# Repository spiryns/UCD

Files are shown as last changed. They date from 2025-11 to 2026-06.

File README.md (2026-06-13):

# SensePath
### Ear-free, intuitive navigation indoors

🛠️ Built by **Sam Piryns**, **Titus Impens**, **Han Deburchgraeve**  
🔥 Supervised by `prof. dr. Bas Baccarne`, `Yannick Christiaens` & `Wouter Devriese`  
🌱 Grown at `Ghent University` 🏛️ `Industrial Design Engineering` ([project overview](https://github.com/basbaccarne/human-centered-design))

*Juni 2026*

---

## Introductie

Mensen die blind of slechtziend zijn navigeren buitenshuis relatief goed met GPS, maar in grote publieke gebouwen (stations, ziekenhuizen, campussen) valt die ondersteuning weg. Vooral op kruispunten, splitsingen en bij tijdelijke omleidingen leidt dit tot twijfel, extra mentale belasting en afhankelijkheid van hulp van anderen.

We onderzochten dit via deskresearch en benchmarking van bestaande (indoor) navigatieoplossingen, en via user interviews en feedbackmomenten met gebruikers en organisaties uit de blinden- en mobiliteitswereld. Daaruit kwamen duidelijke noden naar voren: betrouwbare "decision support" op keuzemomenten, zo weinig mogelijk telefoongebruik tijdens het stappen, en discrete feedback die ook in publieke context bruikbaar is.

Onze oplossing is **SensePath**: een **tweedelige witte stok** die wij volledig als systeem leveren. Het onderstuk volgt de conventionele opbouw van bestaande witte stokken (gewicht, lengte, verwisselbare pin-tip), maar heeft bovenaan een **3D-geprinte schroefdraad** op het uiteinde. Daarop wordt ofwel een **tech-handvat** geschroefd dat de elektronica voor haptische navigatiebegeleiding bevat, ofwel een **gewone handgreep** voor wanneer de route gekend is. Op die manier behoudt de gebruiker volledig zijn bestaande stok-ervaring en voegt SensePath alleen toe wat nodig is op onbekende trajecten. Het tech-handvat is gekoppeld aan een eenvoudige app-workflow en vertaalt route-informatie naar haptische begeleiding op het juiste moment (bv. bij keuzes en bochten), zodat de gebruiker "hands-free, heads-up" kan blijven bewegen met de stok als primair hulpmiddel. Zo maakt SensePath indoor navigatie zelfstandiger, rustiger en betrouwbaarder.

<p align="center">
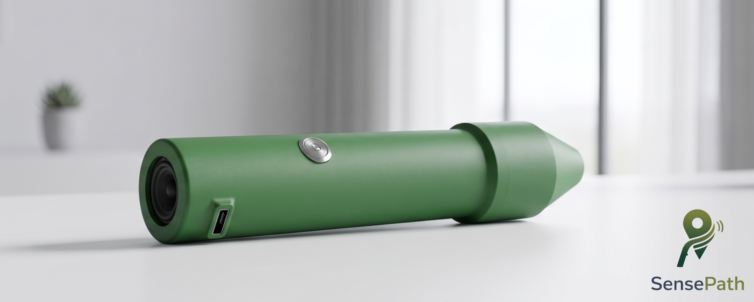
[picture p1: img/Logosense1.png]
SensePath logo
  
</p>

---

## Inhoudstafel

**Op deze pagina**

1. [Introductie](#introductie)
2. [Methodologie](#methodologie)
3. [Conclusie](#conclusie)
4. [Kritische reflectie](#kritische-reflectie)
5. [Noot inzake het gebruik van AI](#noot-inzake-het-gebruik-van-ai)
6. [Bijlagen](#bijlagen)
7. [Bronnen](#bronnen)
8. [Licentie](#licentie)

**Verdieping per fase** (Double Diamond)

1. [Discovery](docs/discovery.md)
2. [Definition](docs/definition.md)
3. [Design Requirements](docs/design_requirements.md)
4. [Develop 1](docs/develop_1.md) 
5. [Develop 2](docs/develop_2.md) 
6. [Develop 3](docs/develop_3_overzicht.md) 
7. [Deliver](docs/deliver.md) 

---

## Methodologie

Dit project volgt de **Double Diamond** aanpak (Discover, Define, Develop, Deliver), met nadruk op gebruikersgericht ontwerpen en iteratieve validatie. De tijdslijn hieronder toont de fasen, test-waves met sample-grootte (N) en de drie kritische pivots die het ontwerp stuurden.

```mermaid
timeline
    title SensePath → Double Diamond met test-waves en pivots
    section Discovery
        Okt 2025  : User interviews (N=3)
                  : Benchmarking 11 systemen
    section Definition
        Nov 2025  : Wave 1 conceptvalidatie (N=5)
        Dec 2025  : Wave 2 verfijning + MoSCoW (N=5)
                  : Pivot → volledige stok wordt afneembaar handvat
    section Develop
        Mrt 2026  : Develop 1 functionele tests (N=5)
        Apr 2026  : Develop 2 usability + ergonomie (N=5)
                  : Pivot → 3 trilmotoren wordt 1 LRA + DRV2605L
        Mei 2026  : Develop 3 microinteracties + CMF (N=5)
                  : Pivot → 10 trilpatronen wordt 3 kernsignalen (M4 M6 M9)
    section Deliver
        Jun 2026  : Validatieplan GPS-precisie en autonome wandeling
                  : Open vraag → Wizard-of-Oz wordt autonoom systeem
```

### Discovery (problem space)

In de discoveryfase werd de probleemruimte verkend via:

- **User interviews**: fricties, routines, copingstrategieën en contextfactoren identificeren (drukte, tijdelijke werken, knooppunten).
- **Deskresearch en benchmarking**: bestaande navigatie- en mobiliteitsoplossingen in kaart brengen en analyseren op feedbackmodaliteit, infrastructuurbehoefte, betrouwbaarheid en schaalbaarheid.

De resultaten werden samengebracht tot een probleemdefinitie, een eerste set **design requirements** en een initiële **PRD**. → 📄 [Volledige Discovery](docs/discovery.md)

### Definition (solution space)

In de definitionfase werd het concept getoetst en aangescherpt via **iteratief prototypen en testen** in twee waves:

- **Wave 1**: Vroege conceptvalidatie met low- tot mid-fidelity prototypes en Wizard-of-Oz scenario's. Focus op begrijpelijkheid, wenselijkheid en aanvaardbaarheid van de conceptrichting.
- **Wave 2**: Verfijning van interactie en feedback met nadruk op minimale smartphone-interactie, haptische feedback als primaire modaliteit, en een fail-safe workflow. Inclusief MoSCoW-prioritering en obstakeldetectie-observatietest.

→ 📄 [Volledige Definition](docs/definition.md)

### Develop (semester 2)

Technische uitwerking, interaction design, prototyping met oplopende fideliteit en usability testing in iteraties, verspreid over drie develop-iteraties. → 📄 [Develop 1](docs/develop_1.md) · [Develop 2](docs/develop_2.md) · [Develop 3](docs/develop_3_overzicht.md)

### Deliver (semester 2)

Finale validatie in realistische omgevingen, afronding prototype en documentatie. → 📄 [Volledige Deliver](docs/deliver.md)

📄 [Volledige methodologie](docs/methodologie.md)

---

## Conclusie

SensePath is een **tweedelige witte stok**: een conventioneel onderstuk met verwisselbare pin-tip en een **tech-handvat dat erop schroeft** via een 3D-geprinte schroefdraad. Dezelfde schroefverbinding accepteert ook een gewone handgreep, zodat de gebruiker dagelijks kan kiezen tussen tech-grip (onbekende routes) en standaard-grip (gekende routes) zonder dat hij van stok hoeft te wisselen. Het tech-handvat vertaalt routebeslissingen naar discrete haptische signalen in de hand. Drie kerncomponenten dragen het concept: één trilmotor die drie onderscheidbare microinteracties (obstakel, koersafwijking, bocht-aankondiging) levert, een sferisch kompaselement in de laagste gleufpositie dat continue richting voelbaar maakt via een servo-aandrijving, en de modulaire schroefverbinding die het hele systeem omkeerbaar maakt.

Waarom dit het juiste antwoord is op het probleem uit Discovery, is geen kwestie van technologie maar van **positionering**. SensePath vervangt het stok-gebruik niet ; we behouden de conventionele stok-opbouw en voegen alleen toe wat nodig is. Het onderstuk blijft de primaire obstakeldetector, het tech-handvat levert wat de stok zelf niet kan: oriëntatie op keuzemomenten zonder dat het gehoor of de smartphone-aandacht ingezet moet worden in het default-gebruik. Een opt-in spraak-fallback (default uit) bestaat als noodvariant. Daarmee adresseert het ontwerp de drie pijnpunten die de Discovery-interviews scherp maakten: onzekerheid aan knooppunten, de wens om het gehoor vrij te houden in publieke context, en de minimale-telefoon-eis tijdens het stappen.

De keuzes die deze positionering dragen, zijn telkens empirisch onderbouwd: de evolutie van 3 motoren naar 1 trilmotor (Develop 2), de versmalde gleuf zodat het kompas in de handpalm blijft (Develop 2), de reductie van 10 naar 3 trilpatronen (Develop 3), de keuze voor TPE Shore 65A overmold (Develop 3 CMF-deepdive). Voor de eindvalidatie wordt het kompas via een mini-servo aangestuurd, die de doelrichting **draadloos** ontvangt van een **aparte controller-module** die de testleider bedient ; daarmee kan het geheel realistisch getest worden zonder dat eerst een autonoom GPS-systeem geïntegreerd moet zijn. Volledige onderbouwing in [docs/design_requirements.md](docs/design_requirements.md).

Het MVP-prototype bestaat uit **drie onderdelen**: het stok-onderstuk, het tech-handvat dat erop schroeft, en de **besturing** — de fysieke Wizard-of-Oz controller-module (eigen XIAO ESP32-C3, batterij en KY-040 encoder, draadloos via ESP-NOW) samen met de digitale software (firmware op handvat en controller + telefoon-app). Het rapport onderscheidt bewust **het beoogde eindproduct** (productie-vorm met hoog-nauwkeurige RTK GNSS via FLEPOS / WALCORS, smartphone-app, ToF-obstakeldetectie en productie-materialen) van **ons MVP-prototype** (academisch deliverable met PLA-print, aparte controller-module als Wizard-of-Oz vervanger voor GPS, en bewust geen obstakeldetectie). Beide niveaus en de vertaalstap ertussen worden uiteengezet in de [Deliver](docs/deliver.md)-sectie. Voor de open onderzoeksvragen en aanbevelingen voor vervolgwerk: zie [Kritische reflectie](#kritische-reflectie).

<p align="center">
  Render van SensePath in gebruik bij indoor navigatie
  <br/><em>SensePath in gebruik: indoor navigatie met de tweedelige witte stok.</em>
</p>

---

## Kritische reflectie

Dit project levert een prototype af dat zijn kerninteractie heeft gevalideerd, maar laat tegelijk vijf open vragen achter die mee bepalen hoe SensePath zich vanaf hier verder kan ontwikkelen. Per-fase reflecties staan binnen [Develop 1](docs/develop_1.md#kritische-reflectie-develop-1), [Develop 2](docs/develop_2.md#kritische-reflectie-develop-2) en [Develop 3](docs/develop_3_overzicht.md#kritische-reflectie-develop-3) ; deze synthese trekt ze samen tot aanbevelingen voor vervolgwerk.

**Sample-grootte en doelgroep-heterogeniteit**. De cumulatieve N over alle Develop-fasen blijft beperkt (Develop 1 N=5, Develop 2 N=5, Develop 3 N=3 blinde + N=2 geblinddoekte ziende controles). De convergentie tussen Mario en Herman op richtinginformatie-in-patroon is sterk, maar Jelle's tegengestelde voorkeur toont dat de doelgroep heterogeen is. Aanbeveling: een vervolgstudie met N=15 → 20 over verschillende leeftijdscategorieën en tech-affiniteitsniveaus om de instelbaarheids-vraag te kwantificeren.

**De Wizard-of-Oz ↔ autonoom systeem vertaling**. 90% van de gemeten fouten in Develop 1 was herleidbaar tot wizard-timing, niet tot gebruikersgedrag of feedbackkwaliteit. Onze test-instrumentatie zit daarmee tussen het ontwerp en de waarheid. Aanbeveling: de finale validatie moet plaatsvinden met een autonoom systeem (GPS- of opgenomen-route-gestuurd) zodat het foutpercentage de feedbackkwaliteit reflecteert in plaats van de wizard-snelheid.

**CMF-deepdive analytisch, niet empirisch**. De keuzes voor TPE Shore 65A overmold, fijne radiale ribbels, POM-knoppen en aluminium pin scoren hoog op weegtabellen onderbouwd met literatuur, maar werden niet als gecombineerd prototype getest met eindgebruikers. Aanbeveling: één-op-één fysieke variant 3D-printen in finale materialen en blind laten beoordelen door dezelfde testers, om de CMF-keuzes empirisch te bevestigen.

**Indoor-focus vs outdoor-robuustheid**. De huidige use case is indoor wayfinding, maar GPS-precisie is buiten de scope van Develop 3 niet getoetst en regen/handschoenen evenmin. Herman's winter-zorg ("ik vrees dat ons pinnetje in de winter niet voelbaar zal zijn") en zijn vraag over uur-plus wandelingen zijn onbewezen aannames. Aanbeveling: outdoor field-test in wisselende weersomstandigheden met sessies van minstens 45 minuten, plus een vervangbare pin-tip uit verschillende materialen (TPE-soft, TPE-hard, rubber).

**Stations als gerichte use-case**. Alle drie de blinde testers wezen spontaan op stations als doel-context. Dit suggereert dat een gerichte go-to-market (stations + ziekenhuizen + campussen) sterker is dan een algemene indoor-positionering. Deze pivot ligt buiten de academische scope van dit project maar verdient verkenning bij een eventuele product-vervolg-traject (VLAIO, RIZIV-terugbetaling, samenwerking NMBS-toegankelijkheid).

Deze vijf punten zijn niet beperkingen van het ontwerp, maar van de manier waarop we het tot nu hebben kunnen valideren. Ze definiëren mee de onderzoeksagenda voor wie dit project zou verderzetten.

---

## Noot inzake het gebruik van AI

Binnen dit project werden meerdere AI-tools ingezet als ondersteunend hulpmiddel:

- **Tekst en rapportage**: Claude (Anthropic) werd gebruikt om ruwe notities en onderzoeksdata te structureren tot leesbare paragrafen en om teksten taalkundig te verfijnen. De inhoudelijke keuzes, analyses en conclusies zijn steeds door het team zelf gemaakt.
- **Benchmarking en analyse**: AI werd ingezet om publiek beschikbare informatie samen te vatten, vergelijkingscriteria te structureren en eerste analyses te genereren. Alle bevindingen werden handmatig geverifieerd.
- **Storyboard**: Het script werd geschreven met Claude Code, image direction via ChatGPT (GPT-4o), en de uiteindelijke beeldgeneratie via NanoBanana (Gemini 3 Pro Image).
- **Codering**: Claude en Gemini werden gebruikt voor ondersteuning bij de ESP32-firmware en de Wizard-of-Oz controller-app.

AI werd **niet** ingezet voor het uitvoeren of analyseren van user interviews, het nemen van ontwerpbeslissingen, of het formuleren van design requirements. Deze zijn volledig gebaseerd op eigen gebruikersonderzoek en teamreflectie.

> *"All content in this document has been reviewed and approved by the author. AI tools were used solely to support text processing, coding, and image editing, not for generating research data or conclusions."*

---

## Bijlagen

### Verdieping per fase

| Fase | Pagina |
|---|---|
| Discovery | [docs/discovery.md](docs/discovery.md) |
| Definition | [docs/definition.md](docs/definition.md) |
| Design Requirements | [docs/design_requirements.md](docs/design_requirements.md) |
| Develop 1 | [docs/develop_1.md](docs/develop_1.md) |
| Develop 2 | [docs/develop_2.md](docs/develop_2.md) |
| Develop 3 (overzicht) | [docs/develop_3_overzicht.md](docs/develop_3_overzicht.md) |
| Develop 3 (UX & Service Design) | [docs/develop_3.md](docs/develop_3.md) |
| Deliver | [docs/deliver.md](docs/deliver.md) |
| Methodologie | [docs/methodologie.md](docs/methodologie.md) |

### Discovery

| Document | Link |
|---|---|
| Interview protocol | [Interview - protocol - SensePath.docx](reports%20and%20protocols/Interview%20-%20protocol%20-%20SensePath.docx) |
| Onderzoeksrapport interviews | [Onderzoeksrapport_user_interviews_SensePath.docx](reports%20and%20protocols/Onderzoeksrapport_user_interviews_SensePath.docx) |
| Benchmarking protocol | [Benchmarkingprotocol_SensePath.docx](reports%20and%20protocols/Benchmarkingprotocol_SensePath.docx) |
| Benchmarking rapport | [Benchmarkingrapport_SensePath.docx](reports%20and%20protocols/Benchmarkingrapport%20_SensePath.docx) |

### Definition

| Document | Link |
|---|---|
| Wave 1 → Protocol | [testprotocol_define_WAVE1.pdf](reports%20and%20protocols/testprotocol_define_WAVE1.pdf) |
| Wave 1 → Rapport | [Report_define_WAVE1.pdf](reports%20and%20protocols/Report_define_WAVE1.pdf) |
| Wave 2 → Protocol | [testprotocol_define_WAVE2.pdf](reports%20and%20protocols/testprotocol_define_WAVE2.pdf) |
| Wave 2 → Rapport | [Report wave 2.pdf](reports%20and%20protocols/Report%20wave%202.pdf) |

### Develop

| Document | Link |
|---|---|
| Develop 1 → Rapport | [Report_SensePath_Develop_1.pdf](reports%20and%20protocols/Report_SensePath_Devolop_1.pdf) |
| Develop 1 → Protocol | [protocol_sensepath_develop1.docx](reports%20and%20protocols/protocol_sensepath_develop1.docx) |
| Develop 2 → Protocol | [protocol_sensepath_develop2_PDF.pdf](reports%20and%20protocols/protocol_sensepath_develop2_PDF.pdf) |
| Develop 2 → Rapport | [Rapport_Dev2_PDF.pdf](reports%20and%20protocols/Rapport_Dev2_PDF.pdf) |
| Develop 3 → Protocol | [protocol_sensepath_develop3_PDF.pdf](reports%20and%20protocols/protocol_sensepath_develop3_PDF.pdf) |
| Develop 3 → Rapport | [rapport_sensepath_develop3.pdf](reports%20and%20protocols/rapport_sensepath_develop3.pdf) |
| Develop 3 → UX & Service Design uitwerking | [develop_3.md](docs/develop_3.md) |
| Develop 3 → Service Blueprint | [service_blueprint.png](docs/develop_3/img/service_blueprint.png) |
| Develop 3 → Customer Journey Map | [customer_journey.png](docs/develop_3/img/customer_journey.png) |
| Develop 3 → Stakeholder Map | [stakeholder_map.png](docs/develop_3/img/stakeholder_map.png) |
| Develop 3 → Norman's drie lagen | [norman_layers.png](docs/develop_3/norman_layers.png) |
| Develop 3 → Emotion Map | [emotion_map.png](docs/develop_3/emotion_map.png) |
| Develop 3 → Microinteractions overzicht | [microinteractions.png](docs/develop_3/microinteractions.png) |

### Deliver

| Document | Link |
|---|---|
| Bill of Materials | [docs/bom.md](docs/bom.md) |
| Schakelschema | [docs/wiring.md](docs/wiring.md) |
| Build guide | [docs/build_guide.md](docs/build_guide.md) |
| Software-architectuur | [docs/software.md](docs/software.md) |
| CAD-bestanden | [cad/](cad/) |
| Volledig 3D-model handvat (STEP) | [cad/Finaal Prototype.stp](cad/Finaal%20Prototype.stp) |
| CAD-exports (STL per onderdeel) | [cad/exports/](cad/exports/) |
| Firmware handvat | [src/firmware/handle/main.cpp](src/firmware/handle/main.cpp) |
| Firmware controller | [src/firmware/controller/main.cpp](src/firmware/controller/main.cpp) |
| Telefoon-app | [src/app/](src/app/) |

---

## Bronnen

### Wetenschappelijke literatuur

- Liu, G., Yu, T., Yu, C., Xu, H., Xu, S., Yang, C., Wang, F., Mi, H., & Shi, Y. (2021). Tactile Compass: Enabling visually impaired people to follow a path with continuous directional feedback. *Proceedings of the 2021 CHI Conference on Human Factors in Computing Systems*. ACM. https://doi.org/10.1145/3411764.3445644
- Guerreiro, J., Ahmetovic, D., Sato, D., Kitani, K., & Asakawa, C. (2019). Airport accessibility and navigation assistance for people with visual impairments. *Proceedings of the 2019 CHI Conference on Human Factors in Computing Systems*, 1-14.
- Slade, P., Tambe, A., & Kochenderfer, M. J. (2021). Multimodal sensing and intuitive steering assistance improve navigation and mobility for people with impaired vision. *Science Robotics, 6*(59), eabg6594.
- Martiniello, N., et al. (2020). *Aesthetics and perceived stigma of assistive technology for people with visual impairment.* (Geciteerd in de Develop 3 UX- en CMF-onderbouwing.)
- Alary, F., et al. (2008). *Tactile acuity in the blind: a psychophysical study using a two-dimensional angle discrimination task.* Experimental Brain Research. (Tactiele drempelwaarden bij blinde gebruikers.)
- Skedung, L., et al. (2018). *Tactiele perceptie van fijne oppervlaktetexturen.* (Leesbaarheid van grip-texturen voor oudere handen.)
- Shostack, G. L. (1984). Designing services that deliver. *Harvard Business Review, 62*(1), 133-139.
- Fogg, B. J. (2009). A behavior model for persuasive design. *Proceedings of the 4th International Conference on Persuasive Technology (Persuasive '09)*. ACM.
- Vaes, K. (2014). *Product Stigmaticity: Understanding, measuring and managing product-related stigma* [Doctoraatsproefschrift, TU Delft & Universiteit Antwerpen].
- Wertheimer, M. (1923). *Untersuchungen zur Lehre von der Gestalt* (Gestalt-perceptiewetten).

### Ontwerptheorie & boeken

- Norman, D. A. (2013). *The Design of Everyday Things: Revised and Expanded Edition.* Basic Books.
- Norman, D. A. (2004). *Emotional Design: Why We Love (or Hate) Everyday Things.* Basic Books.
- Norman, D. A. (2011). *Living with Complexity.* MIT Press.
- Saffer, D. (2013). *Microinteractions: Designing with Details.* O'Reilly Media.
- Eyal, N. (2014). *Hooked: How to Build Habit-Forming Products.* Portfolio / Penguin.
- Walter, A. (2011). *Designing for Emotion.* A Book Apart.

### Normen, standaarden & richtlijnen

- ISO 9999:2016. *Assistive products for persons with disability — Classification and terminology.* International Organization for Standardization.
- World Health Organization. (2016). *Priority assistive products list (APL)* en *Assistive product specifications (APS).* WHO.
- World Health Organization. (2023). *Blindness and vision impairment.* Geraadpleegd van https://www.who.int/news-room/fact-sheets/detail/blindness-and-visual-impairment
- Gordon, C. C., et al. (2014). *2012 Anthropometric Survey of U.S. Army Personnel: Methods and Summary Statistics (ANSUR II).* U.S. Army Natick Soldier RD&E Center.

### Methodologie

- Design Council. (2005). *The Double Diamond: A universally accepted depiction of the design process.* Geraadpleegd van https://www.designcouncil.org.uk/double-diamond

### Positionerings-infrastructuur

- Digitaal Vlaanderen. *FLEPOS — Flemish Positioning Service* (RTK GNSS-correcties via NTRIP).
- Service public de Wallonie (SPW). *WALCORS — Walloon Continuously Operating Reference Stations.*

### Cursusmateriaal (Gebruiksgericht Ontwerpen, Universiteit Gent)

- Baccarne, B. (2025-2026). *Project Gebruiksgericht Ontwerpen — cursusmateriaal* (IxD / Usability / UX, Cognition, Human Senses & Interfaces, Social Interaction & Behaviour, Evaluation Methods). Universiteit Gent. https://github.com/basbaccarne/human-centered-design

### AI-tools

- Anthropic. (2026). Claude (Claude Opus 4.7) [Groot taalmodel]. https://claude.ai
- OpenAI. (2026). ChatGPT (GPT-4o) [Groot taalmodel]. https://chat.openai.com
- Google DeepMind. (2026). Nano Banana Pro (Gemini 3 Pro Image) [AI-beeldgeneratiemodel].

---

## Licentie

This repository contains both software and design materials created as part of an industrial design engineering project at Ghent University.

- **Software and code:** [MIT License](LICENSE-MIT)
- **Design, documentation, CAD, and media:** [CC BY 4.0 License](LICENSE)

You are free to reuse and build upon this work, both commercially and non-commercially, as long as proper attribution is given to the original authors.

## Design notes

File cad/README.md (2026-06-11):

# CAD → SensePath

Deze map bevat de CAD-bestanden van de SensePath handvat-iteraties. De primaire werkomgeving was **Siemens NX**, dus de bron-bestanden zijn `.prt` en de samengevoegde assemblies zijn als `.zip` bewaard. Voor externe bouwers (zonder NX-licentie) staan exports naar **STL** en **STEP** in [exports/](exports/).

---

## Inhoud

| Bestand | Iteratie | Beschrijving |
|---|---|---|
| [protoype_handvat_trillingmotoren.prt](protoype_handvat_trillingmotoren.prt) | **Develop 3 (finaal)** | Handvat met sferisch kompas-contactoppervlak in laagste gleufpositie. Inclusief uitsparingen voor XIAO ESP32-S3, DRV2605L, LRA en POM-knoppen. |
| [quick&dirty_trillingshandvat.prt](quick&dirty_trillingshandvat.prt) | Develop 1 → 2 | Vroege functionele variant met meervoudige motor-opstelling. Behouden voor traceability. |
| [Bol_mechanisme_motor.zip](Bol_mechanisme_motor.zip) | Develop 2 | Assembly van het kompas-mechanisme met bol op aluminium pin. |
| [Quick en dirty mechanisch bolletje.zip](Quick%20en%20dirty%20mechanisch%20bolletje.zip) | Develop 1 | Eerste mechanische kompas-test. |
| [sensepathsem1final.zip](sensepathsem1final.zip) | Semester 1 (Definition) | Volledige assembly aan het einde van semester 1 ; obsoleet vanaf Develop 1. |

---

## Welke file is het Develop 3 finaal ontwerp?

**`protoype_handvat_trillingmotoren.prt`** is het bestand dat overeenkomt met het prototype beschreven in [../docs/bom.md](../docs/bom.md) en het [Develop 3-hoofdstuk in de README](../README.md#develop-3). Specifiek:

- Sferisch kompas-contactoppervlak (uit Develop 2 selectie)
- Laagste gleufpositie ; kompas binnen handpalm, niet eruit wijkend
- Inwendige uitsparingen voor:
  - XIAO ESP32-S3 microcontroller
  - Adafruit DRV2605L breakout
  - Trilmotor tegen hypothenar-zijde (LRA in productie-vorm, coin vibratiemotor 10 × 2.7 mm in MVP-prototype)
  - MG90S servo voor mechanisch kompas
  - Bedieningselementen aan de achterkant (POM-knoppen volgens CMF-deepdive in productie-vorm; HOTUT IP67 metalen drukknop + SS12F44 schuifschakelaar in MVP-prototype voor robuust testen)
  - Onderaan: mee-geprinte schroefdraad voor schroefverbinding met het stok-onderstuk

CMF-specs (uit Develop 3 CMF-deepdive, productie-doel):
- Core: **PA6 unfilled** ; slag- en slijtvast voor dragend gedeelte (in MVP-prototype 3D-geprint in PLA voor snelheid)
- Overmold (gepland): **TPE Shore 65A** ; zacht-tactiel comfort (niet aanwezig in MVP-print)
- Grip-textuur: fijne radiale ribbels
- Knoppen: POM (glad, kleurvast) ; in MVP-prototype vervangen door HOTUT IP67 voor robuust testen
- Kompas-pin: aluminium met optionele TPE-tip (vervangbaar)

---

## Exports voor externe bouwers

`.prt` bestanden zijn alleen leesbaar in Siemens NX (commerciële licentie). Voor reproduceerbaarheid staan format-onafhankelijke exports in [exports/](exports/):

- `*.stl` ; direct 3D-printbaar (geen editing mogelijk)
- `*.step` ; bewerkbaar in elke CAD-tool (Fusion 360, SolidWorks, FreeCAD)

> Status: STL/STEP-exports worden in de Deliver-fase toegevoegd door het team. Zie [exports/README.md](exports/README.md) voor de naming-conventie en TODO-status.

---

## Volgorde van CAD-iteraties

1. **Semester 1**: `sensepathsem1final.zip` ; volledige slimme stok met ingebouwde elektronica. Verlaten in Develop 1 wegens te complexe productarchitectuur.
2. **Develop 1**: `Quick en dirty mechanisch bolletje.zip` ; eerste validatie van mechanisch kompas-concept.
3. **Develop 1 → 2**: `quick&dirty_trillingshandvat.prt` ; functionele variant met 3 trilmotoren ; verlaten in Develop 2 voor 1-LRA opstelling.
4. **Develop 2**: `Bol_mechanisme_motor.zip` ; assembly met sferisch kompas (uit Develop 2 selectie).
5. **Develop 3 (huidig)**: `protoype_handvat_trillingmotoren.prt` ; gleuf versmald, bedieningselementen geïntegreerd, klaar voor finale validatie in Deliver.

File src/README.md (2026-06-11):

# SensePath source code

## Firmware

De huidige werkende prototypefirmware staat in:

- [`firmware/sensepath_esp32`](firmware/sensepath_esp32)

Deze ESP32-sketch start een eigen wifi-accesspoint, bedient de DRV2605L haptiekdriver en biedt een kleine webcontroller voor de SensePath M-patronen.

Korte flow:

1. Upload `firmware/sensepath_esp32/sensepath_esp32.ino` naar een ESP32.
2. Verbind met wifi `SensePath` met wachtwoord `sensepath`.
3. Open `http://192.168.4.1/`.

Zie de README in de firmwaremap voor pinnen, libraries en API-routes.

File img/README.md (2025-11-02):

use this folder to story the media files you show in your report you can show them using, e.g.

```
<p align="left">
  <img src="img/prototype1" width="32%">
  <img src="img/prototype2" width="32%">
  <img src="imgprototype2" width="32%">
</p>
```

- ❗Make sure you have asked for permission when you show persons
- ❗If it's not needed to show the faces of people (camera angle or blur), prefer this.
- 💡Animated gifs can be used to show animations.

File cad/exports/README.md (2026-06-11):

# CAD exports → STL

3D-print-klare STL-exports van het Develop 3 finale ontwerp. De NX-bronbestanden (`.prt` + zips) staan in [../](../).

## Bestanden

| Bestand | Onderdeel |
|---|---|
| `behuizingstok_3Dprint.stl` | Hoofdbehuizing van het tech-handvat (stok-zijde) |
| `opzetstukbehuizing_3Dprint.stl` | Opzetstuk-behuizing bovenaan het handvat |
| `servobehuizing_3Dprint.stl` | Behuizing voor de MG90S servo (kompas-aandrijving) |
| `Kompas_3Dprint.stl` | Sferisch kompaselement, koppelt op de servo-as |
| `elektronica_3Dprint.stl` | Houder/frame voor de elektronica in het handvat |
| `boxhold_3Dprint.stl` | Behuizing van de Wizard-of-Oz controller-module |

Aanbevolen print-instellingen (laagdikte, infill, oriëntatie, materiaal) staan in de [build guide](../../docs/build_guide.md) → Sectie 1.

## Opnieuw exporteren (Siemens NX)

1. Open het betreffende bronbestand in [../](../) in NX.
2. File → Export → STL → kies "Faceted Body" → tolerance 0.05 mm → output naar `<onderdeel>_3Dprint.stl`.

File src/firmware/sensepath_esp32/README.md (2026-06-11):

# SensePath handvat-firmware (XIAO ESP32-S3)

Firmware voor de handvat-module. De Wizard-of-Oz controller heeft eigen firmware op een XIAO ESP32-C3 (aparte sketch, draadloos via ESP-NOW gekoppeld).

> De `.ino`-broncode in deze map dateert van vóór de migratie naar XIAO en gebruikt nog de oorspronkelijke ESP32 DevKit-pinout (SDA = 21, SCL = 22). Bij compilatie voor de finale MVP-build moeten de I2C-pinconstanten aangepast worden naar de XIAO-mapping (SDA = D4 = GPIO 5, SCL = D5 = GPIO 6) en moet een ESP-NOW receiver toegevoegd worden. Zie [docs/wiring.md](../../../docs/wiring.md) en [docs/build_guide.md](../../../docs/build_guide.md) voor de volledige pinout en build-procedure.

## Hardware (alleen het handvat)

- Seeed Studio XIAO ESP32-S3 (WiFi + BLE 5.0, onboard Li-Po laadondersteuning)
- Adafruit DRV2605L via I2C (ERM-modus voor coin vibratiemotor)
- Coin vibratiemotor 10 × 2.7 mm op de DRV2605L OUT-pinnen
- MG90S servo voor mechanisch kompas (PWM via D9)
- HOTUT drukknop op D3 (RTC-GPIO 4) ; dubbele rol: korte druk = functie (start/stop, overzicht), **lange druk (≥3 s)** = `esp_deep_sleep_start()`, druk uit deep-sleep = wake via `esp_sleep_enable_ext0_wakeup(GPIO_NUM_4, 0)`. Geen rocker-switch op het handvat (physical-design constraint), dus deze knop is de enige user-facing power-control.
- Optioneel: MAX98357A I2S audio-versterker + speaker (BCLK = D6, LRC = D7, DIN = D8, SD = D10 als software-gated power-gate, GAIN naar GND voor 15 dB)

> De KY-040 roterende encoder zit **niet** op het handvat. Die hangt aan een aparte controller-module (XIAO ESP32-C3) die via ESP-NOW de encoder-positie naar deze ESP32-S3 verstuurt. De handvat-firmware ontvangt de richtings-updates en stuurt op basis daarvan de MG90S servo aan.

## I2C-pinout (finale XIAO-build)

| Signaal | XIAO pin |
|---|---:|
| SDA | D4 (GPIO 5) |
| SCL | D5 (GPIO 6) |
| 3V3 | 3V3 |
| GND | GND |

## Arduino IDE

1. Board manager URL toevoegen: `https://raw.githubusercontent.com/espressif/arduino-esp32/gh-pages/package_esp32_index.json`
2. Installeer `esp32` board package (versie 2.0.14 of hoger).
3. Installeer libraries:
   - `Adafruit DRV2605 Library`
   - `ESP32Servo` (voor MG90S aansturing)
   - `esp_now.h` (intern in ESP-IDF / Arduino-ESP32 core) voor het ontvangen van richtingsdata van de controller-module
4. Open `sensepath_esp32.ino`.
5. Pas de I2C-pinconstanten aan (zie note hierboven).
6. Kies Tools → Board → ESP32 Arduino → XIAO_ESP32S3.
7. Upload naar de XIAO via USB-C.

## Gebruik

Na opstarten verschijnt in Serial Monitor:

```text
SensePath start
DRV2605L gevonden
AP gestart, IP: 192.168.4.1
Webserver start
```

Verbind daarna met wifi:

- SSID: `SensePath`
- Wachtwoord: `sensepath`
- Controller: `http://192.168.4.1/`

## API

- `GET /api/status`
- `GET /api/pattern?name=m1`
- `GET /api/pattern?name=m4&direction=left`
- `GET /api/pattern?name=m4&direction=right`
- `GET /api/stop`
- `GET /api/intensity?level=low|medium|high`

Ondersteunde patronen: `m1`, `m2`, `m3`, `m4`, `m5`, `m6`, `m7`, `m8`, `m9`. De drie kernsignalen voor de Develop 3 + Deliver tests zijn `m4` (obstakel), `m6` (koersafwijking) en `m9` (bocht-aankondiging).

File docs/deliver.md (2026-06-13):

# SensePath → Deliver

[← Terug naar hoofdpagina](../README.md)

---

## Deliver

De Deliver-fase sluit de Double Diamond door alle inzichten uit Discovery, Definition en Develop 1 → 3 te bundelen tot een samenhangend ontwerp. Bewust onderscheiden we twee niveaus: **het beoogde eindproduct** (de definitieve vorm die SensePath in een real-world deployment zou hebben) en **ons prototype** (de MVP die we als academisch deliverable opleveren om de essentiële interacties te testen). De ontwerpredenen blijven dezelfde; wat verschilt is de scope van de implementatie.

### Het beoogde eindproduct

#### Wat SensePath in productie zou zijn

SensePath in zijn definitieve vorm is een **tweedelige witte stok**. Het onderstuk volgt de conventionele opbouw van bestaande witte stokken (gewicht, lengte-opties, verwisselbare pin-tip), maar heeft bovenaan een **3D-geprinte schroefdraad** op het uiteinde. Het **tech-handvat** heeft een matching mee-geprinte schroefdraad en wordt erop geschroefd. Dezelfde schroefverbinding accepteert ook een conventionele handgreep zonder elektronica, zodat de gebruiker dagelijks kan kiezen tussen tech-grip (onbekende routes) en standaard-grip (gekende routes) zonder dat hij van stok hoeft te wisselen.

In het tech-handvat zit een mechanisch kompaselement met sferisch contactoppervlak dat continue richting voelbaar maakt, aangedreven door een mini-servo en gestuurd door een hoog-nauwkeurige route-engine. Een geïntegreerde trilmotor levert drie haptische microsignalen op de cruciale beslismomenten (obstakel, koersafwijking, bocht-aankondiging). Een ingebouwde obstakeldetectie via ToF-sensoren op hoofd- en voethoogte vangt obstakels op die buiten het bereik van de stok vallen. Een smartphone-app via BLE verzorgt route-input en monitoring. Een interne accu met USB-C opladen maakt de unit autonoom inzetbaar, en een opt-in audio-fallback (speaker of Bluetooth-oortje) staat default uit voor reguliere gebruikers en kan worden ingeschakeld als noodvariant.

#### Hoog-nauwkeurige positionering via FLEPOS / WALCORS

De kerninteractie van SensePath, een continu meedraaiend mechanisch kompas, vereist een positionering binnen ~1 meter rond kruispunten en draaipunten. Standaard smartphone-GPS levert in stedelijke canyons 5 → 10 m foutmarge en is daarvoor onvoldoende. De productie-vorm gebruikt daarom **RTK GNSS-correcties** via de Belgische infrastructuur: **FLEPOS** (Flemish Positioning Service, beheerd door Digitaal Vlaanderen) in Vlaanderen en **WALCORS** in Wallonië. Beide netwerken leveren via NTRIP cm- tot sub-meter-precisie en worden vandaag al gebruikt voor surveying en autonoom rijden. Voor blinde mobiliteit zou een sociale-tarief-licentie (bv. via VLAIO of RIZIV-erkenning) de drempel kunnen wegnemen.

#### Architectuur van het eindproduct

<p align="center">
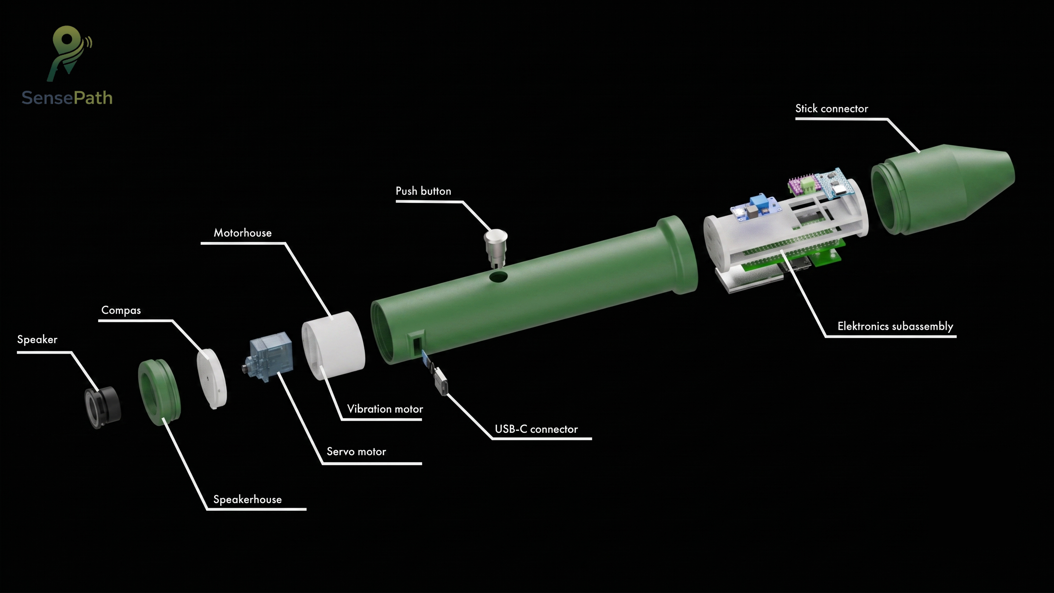
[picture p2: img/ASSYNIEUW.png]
Assembly van het SensePath eindproduct
  
  <br/><em>Assembly-overzicht van het beoogde eindproduct: tech-handvat, kompasmechanisme en stok-onderstuk.</em>
</p>

**Hardware**
- 1× microcontroller met BLE 5.0 + WiFi (productie-equivalent van XIAO ESP32-S3)
- 1× Adafruit DRV2605L haptische motordriver (ADA2305)
- 1× LRA-trilmotor (200 Hz resonance, productie-grade)
- 1× MG90S-equivalente servo voor mechanisch kompas
- 1× sferisch kompaselement, laagste gleufpositie, vervangbare aluminium pin met optionele TPE-tip
- 2× ToF-sensoren (VL53L0X of vergelijkbaar) voor obstakeldetectie op hoofd- en voethoogte
- 1× drukknop + harde aan/uit-switch
- 1× speaker + I2S-versterker voor opt-in audio
- 1× Li-ion accu (1500-2500 mAh) met USB-C laadcircuit + battery management
- 1× MT3608-equivalente boost converter voor de 5 V rail (servo + audio-versterker)

**Behuizing**
- 3D-geprinte of injectie-geperste tech-handvat-core in PA6 unfilled
- TPE Shore 65A overmold met fijne radiale ribbels
- POM-knoppen met visueel-tactiele differentiatie
- Mee-geprinte schroefdraad in het tech-handvat voor de schroefverbinding met de stok
- Olijfgroen (olive green) tech-handvat, contrasterend met de witte stok die wit blijft (ISO 9999 + verkeerswetten)

**Stok-onderstuk**
- Conventioneel ontworpen lange witte stok in productie-grade aluminium of glasvezel
- 3D-geprinte schroefdraad op het top-uiteinde, conform de mee-geprinte schroefdraad in het tech-handvat
- Verwisselbare pin-tip aan het loop-uiteinde, exact zoals bij conventionele witte stokken
- Lengte-opties volgens antropometrie (D1.2)

**Software**
- BLE-app (iOS + Android) met VoiceOver / TalkBack voor route-input, monitoring, batterij-feedback
- Route-engine met FLEPOS / WALCORS NTRIP-correcties
- Drie haptische micropatronen (M4, M6, M9) via DRV2605L
- Servo-aansturing op basis van GPS-route + heading
- Battery feedback via M9-puls bij low-battery
- Opt-in audio-pipeline (default uit)
- Deep-sleep tussen pulses voor batterij-efficiëntie

#### Waarom dit het juiste eindproduct is

Drie principes dragen de productie-vorm:

1. **Conventionele stok-ervaring blijft de basis** ; het onderstuk volgt de bestaande witte-stok-conventie (gewicht, lengte, verwisselbare tip) en blijft primaire obstakeldetector. SensePath voegt via de schroef-modulariteit alleen toe wat nodig is op onbekende routes en vangt via ToF-sensoren obstakels op die buiten het stok-bereik vallen.
2. **Hands-free, heads-up, ear-by-default-free** ; geen smartphone-aandacht tijdens het stappen, geen audio in default-modus.
3. **Minimale cognitive load** ; één tactiel aandachtspunt voor continue feedback, drie maximaal onderscheidbare event-signalen.

Volledige onderbouwing in [design_requirements.md](design_requirements.md).

### Ons prototype → MVP voor academische deliverable

<p align="center">
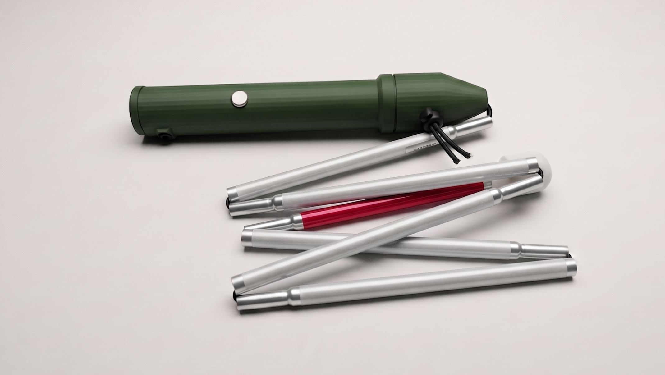
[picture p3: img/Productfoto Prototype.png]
Productfoto van het SensePath MVP-prototype
  
  <br/><em>Productfoto van ons MVP-prototype: tech-handvat op de witte stok.</em>
</p>

Wat we werkelijk gebouwd hebben, ligt bewust onder de productie-scope. Een academisch project van één semester moet de **essentiële design-hypothesen** kunnen testen, niet het volledige product realiseren. Onze prototype-keuzes weerspiegelen die scope-beperking, met telkens een verantwoording voor de versimpeling.

#### Drie onderdelen

Het MVP-prototype is opgesplitst in drie onderdelen:

1. **Stok-onderstuk** ; conventionele lange witte stok waarop we bovenaan een **3D-geprint draadstuk vast hebben geïntegreerd**. De pin-tip aan het loop-uiteinde blijft verwisselbaar zoals bij elke commerciële witte stok.
2. **Tech-handvat** ; schroeft via een mee-geprinte schroefdraad op het stok-onderstuk. Bevat alle handvat-elektronica (zie hieronder).
3. **Besturing** ; bepaalt welke richting en welke signalen het handvat krijgt. De besturing valt uiteen in een **fysieke besturing** (de Wizard-of-Oz controller-module die de testleider bedient) en een **digitale besturing** (de software op het handvat, de controller en de telefoon-app). Zie hieronder.

#### Hardware-realisatie tech-handvat

<p align="center">
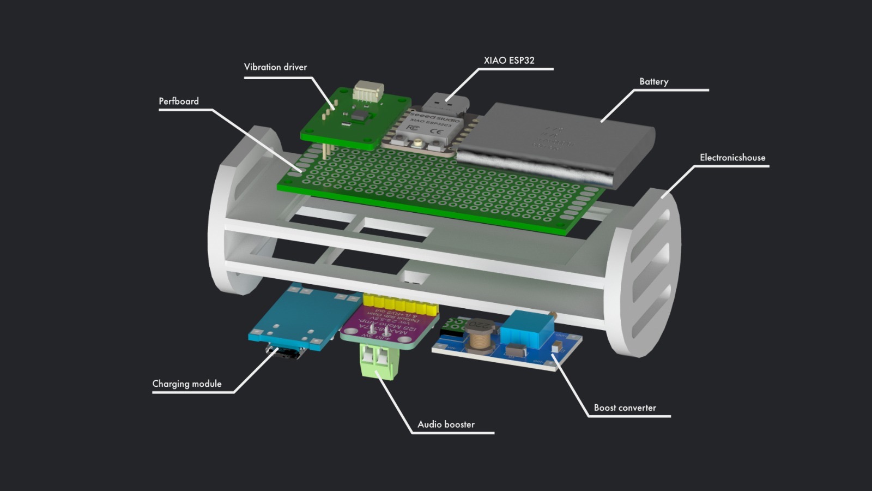
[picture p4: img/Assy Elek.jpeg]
Elektronica-assembly van het tech-handvat (prototype)
  
  <br/><em>Elektronica-assembly van het tech-handvat: XIAO ESP32-S3, DRV2605L, coin vibratiemotor, MG90S servo, MAX98357A audio-amp, MT3608 boost en Li-Po.</em>
</p>

- **3D-print in PLA** in plaats van PA6 + TPE-overmold ; sneller iteratie en lagere kost. De vormfactor en grip-textuur zijn behouden, alleen de materiaal-feel verschilt. CMF-keuzes zijn onderbouwd in Develop 3 maar niet als gecombineerd prototype getest.
- **XIAO ESP32-S3** als microcontroller, ontvangt richting-updates via ESP-NOW van de controller-module.
- **Adafruit DRV2605L haptische motordriver** (ADA2305) ; I2C-gekoppeld aan de XIAO, bevat 123 ingebouwde haptische effecten en stuurt de coin vibratiemotor aan in ERM-modus.
- **Coin vibratiemotor** in plaats van LRA ; goedkoper en breder beschikbaar. Wordt aangedreven door dezelfde DRV2605L (in ERM-modus); de drie haptische microsignalen blijven herkenbaar.
- **MG90S mini-servo** voor aansturing van het mechanisch kompas. Identiek aan de productie-vision.
- **Geen obstakeldetectie** in het prototype. Methodische keuze: het stok-onderstuk blijft de primaire detector, en het toevoegen van ToF-sensors zou een confounding variabele introduceren in de haptische-navigatie-tests die we willen doen. Voor productie is obstakeldetectie volwaardig opgenomen (D2.5 + D2.6).
- **Speaker + MAX98357A I2S-versterker** voor opt-in audio-fallback (default uit via SD-pin door XIAO D10 gegated; MT3608 boost staat altijd aan voor de servo, en SD-pin laag houdt enkel de audio-amp in stand-by).
- **HOTUT IP67 metalen drukknop** met dubbele rol: short-press = start/stop route, double-press = "geef overzicht", long-press (≥3 s) = XIAO gaat in deep-sleep ("uit"-stand), druk uit deep-sleep = wake via EXT0 op RTC-GPIO 4. Geen rocker-switch op het handvat (physical-design constraint in de cap-geometrie); deep-sleep "off" trekt nog ~10 mA quiescent (~4 dagen autonomie in opslag).
- **Interne Li-Po 1000 mAh** + **TP4056 USB-C laadcircuit** ; aparte USB-C laad-poort, firmware-flashen via de eigen USB-C poort van de XIAO.
- **MT3608 boost converter** ; verzorgt de 5 V rail voor de servo en de audio-versterker (staat altijd aan; de audio-amp wordt apart via zijn SD-pin in stand-by gezet).

#### Hardware-realisatie besturing

De **besturing** stuurt het handvat aan en bestaat uit twee complementaire lagen: een **fysieke** laag (de controller die de testleider in handen heeft) en een **digitale** laag (de software die de signalen genereert en doorstuurt). Samen vormen ze de Wizard-of-Oz-brug die een toekomstig autonoom GPS-systeem nabootst.

**Fysieke besturing → Wizard-of-Oz controller-module**

<p align="center">
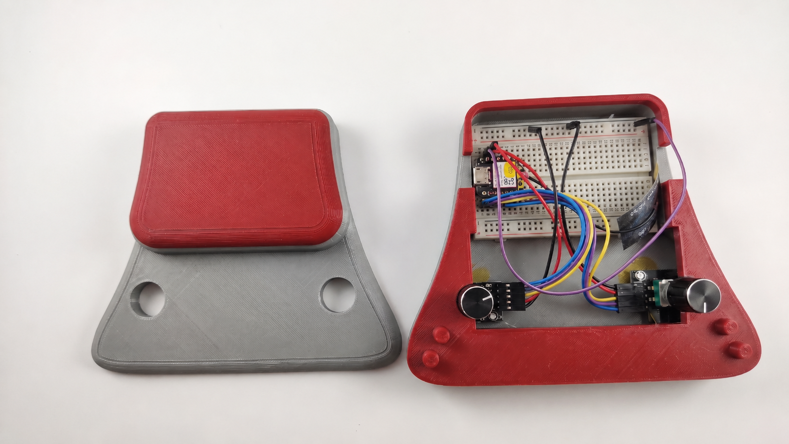
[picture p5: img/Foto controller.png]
Wizard-of-Oz controller-module
  
  <br/><em>De aparte Wizard-of-Oz controller-module: XIAO ESP32-C3 + KY-040 encoder in een 3D-geprinte PLA-behuizing, draadloos via ESP-NOW gekoppeld aan het handvat.</em>
</p>

- **XIAO ESP32-C3** als microcontroller, met eigen firmware ([src/firmware/controller/main.cpp](../src/firmware/controller/main.cpp)). Verstuurt encoder-deltas via ESP-NOW naar het handvat.
- **KY-040 roterende encoder** met geïntegreerde drukknop. De testleider draait de encoder; elke positie-update gaat draadloos naar het handvat dat op zijn beurt de servo aanstuurt.
- **Eigen Li-Po 1000 mAh + TP4056 USB-C laadcircuit + rocker-switch + USB-C laad-poort** ; identieke voedingsschema als het handvat, zonder MT3608 (geen audio nodig op de controller).
- **3D-print PLA case** (~60 × 40 × 25 mm) met encoder bovenaan en switch + USB-C op de zijkant.

Daarmee voelt de testleider mechanische rotatie alsof hij een echte stuurinterface in handen heeft, en is de brug naar een toekomstig autonoom GPS-systeem cleaner gedefinieerd: de wijziging zit niet in het handvat zelf maar in wie/wat de richtingsdata genereert (controller-encoder vs GPS-engine).

**Digitale besturing → software**

De digitale laag vertaalt de fysieke input naar richting, haptiek en audio. Ze bestaat uit de firmware op het handvat ([src/firmware/handle/main.cpp](../src/firmware/handle/main.cpp)), de firmware op de controller ([src/firmware/controller/main.cpp](../src/firmware/controller/main.cpp)) en de toegankelijke telefoon-app ([src/app/](../src/app/)) die het handvat zelf via WiFi serveert. De volledige software-architectuur staat beschreven in [docs/software.md](software.md).

#### Waarom dit voldoende is om de essentiële interacties te valideren

Het prototype test wat het ontwerp daadwerkelijk uniek maakt: de combinatie van een mechanisch kompas in de handpalm met drie discrete haptische signalen op beslismomenten, in samenspel met het stok-onderstuk via de modulaire schroefverbinding. De Wizard-of-Oz controller-module simuleert de toekomstige autonome richtingsbron zonder dat we eerst RTK GNSS hoeven te integreren. De stappen die het prototype overslaat (RTK GNSS-pipeline, productie-materialen, obstakeldetectie, BLE-app) zijn onafhankelijke engineering-uitdagingen die het ontwerp niet veranderen ; alleen de implementatie ervan opschalen naar productie-niveau.

#### Reproduceerbaarheid van het prototype

| Document | Inhoud |
|---|---|
| [bom.md](bom.md) | BOM voor de drie modules (handvat, controller, stok-onderstuk) met productlinks en prijs |
| [wiring.md](wiring.md) | Schakelschema per module + ESP-NOW link + power budget |
| [build_guide.md](build_guide.md) | Stap-voor-stap bouwinstructies (handvat + controller + integratie-test) |
| [Project context/sensepath_wiring_schematic.html](../Project%20context/sensepath_wiring_schematic.html) | Visueel wiring-schema in browser, met beide modules en de draadloze link |
| [cad/](../cad/) | CAD-bronbestanden Siemens NX, het volledige 3D-model van het handvat [Finaal Prototype.stp](../cad/Finaal%20Prototype.stp) (STEP), en STL-exports per onderdeel in [cad/exports/](../cad/exports/) |
| [docs/software.md](software.md) | Software-architectuur: handvat-firmware, controller-firmware en telefoon-app |
| [src/firmware/handle/main.cpp](../src/firmware/handle/main.cpp) | Firmware van het handvat (ESP32-S3): servo-kompas, haptiek, audio en webserver |
| [src/firmware/controller/main.cpp](../src/firmware/controller/main.cpp) | Firmware van de Wizard-of-Oz controller (ESP32-C3): encoder + afslagknop via ESP-NOW |
| [src/app/](../src/app/) | Toegankelijke telefoon-app (browser) voor bestemming, navigatie, live kompas en instellingen |

### Vertaalstap → prototype tegenover eindproduct

Voor elke ontwerpbeslissing maakt de tabel hieronder helder wat **design** is (blijft constant tussen prototype en eindproduct) en wat **scope-keuze** is (verschilt tussen beide).

| Inzicht uit onderzoek | Keuze in eindproduct | Realisatie in ons prototype |
|---|---|---|
| Modulariteit zonder afstand te doen van conventionele stok-ervaring | Tweedelige witte stok: conventioneel onderstuk + 3D-geprinte schroefdraad + tech-handvat (of standaard handgreep) met matching schroefdraad | Conventionele witte stok met 3D-geprint draadstuk + PLA tech-handvat met mee-geprinte schroefdraad (zelfde mechanisch principe) |
| Continue koersfeedback in handpalm | Mechanisch kompas, servo-aangedreven, gestuurd door RTK GNSS-route uit smartphone-app | Mechanisch kompas, servo-aangedreven, gestuurd door een **aparte controller-module** (XIAO ESP32-C3 + KY-040 encoder) die draadloos via ESP-NOW met het handvat verbonden is |
| Sferisch contactoppervlak in laagste gleufpositie | Identiek | Identiek |
| 1 trilmotor + DRV2605L met 3 microinteracties | LRA + DRV2605L (cleaner onset/offset) | Coin vibratiemotor + DRV2605L (zelfde driver, ERM-actuator om kost) |
| 3 kernsignalen M4 / M6 / M9 | Identiek | Identiek |
| PA6 unfilled core + TPE Shore 65A overmold + fijne radiale ribbels | Productie-materialen, injectie-geperst | PLA 3D-print zonder overmold (vorm + textuur identiek, materiaal-feel anders) |
| Hoog-nauwkeurige positionering | RTK GNSS via FLEPOS / WALCORS infrastructuur | Niet aanwezig ; vervangen door encoder-aansturing |
| Smartphone-app voor route-input | Native iOS / Android met VoiceOver / TalkBack | Niet aanwezig ; testleider neemt rol over via fysieke encoder op de aparte controller-module |
| Geïntegreerde obstakeldetectie (D2.5 + D2.6) | ToF-sensoren op hoofd- en voethoogte | Niet in prototype; methodische keuze om confounding te vermijden |
| Battery management + low-power modes | Productie-firmware met deep-sleep, batterij-feedback via M9 | Basisuitvoering: deep-sleep tussen pulses; geen battery-feedback aan gebruiker |
| BLE 5.0 link | Native gekoppeld aan smartphone-app | Hardware aanwezig (XIAO ESP32-S3), nog niet geïmplementeerd in firmware |
| Opt-in audio-fallback | Speaker of Bluetooth-oortje | Speaker + MAX98357A in het handvat, default uit |
| Bediening: 1 drukknop + harde aan/uit | POM-knop met visueel-tactiele differentiatie (CMF Develop 3) + soft-latch power-circuit (smartphone-style) | HOTUT IP67 metalen drukknop met dubbele rol via firmware (short = functie, long = deep-sleep) ; geen aparte rocker omwille van cap-geometrie. Trade-off: ~10 mA quiescent in "uit"-stand i.p.v. echte 0 mA |
| Voeding | Li-ion (1500 → 2500 mAh) + custom PCB met USB-C | Per module: Li-Po 1000 mAh + TP4056 USB-C laad-poort (apart laden van handvat en controller) |
| Wizard-of-Oz aansturing tijdens testen | n.v.t. (in productie GPS-autonoom) | Aparte controller-module: XIAO ESP32-C3 + KY-040 encoder + eigen batterij, ESP-NOW link met het handvat |
| Vervangbare aluminium pin met optionele TPE-tip | Productie-pin + TPE-tip set | Aluminium pin (TPE-tip nog niet gefabriceerd) |
| Witte stok blijft wit, contrast-handvat | Olijfgroen (olive green), contrasterend met de witte stok, ISO 9999 conform | PLA in olijfgroen (olive green) |

Zie [design_requirements.md](design_requirements.md) voor de formele requirement-mapping.

### Finale validatie van het prototype

Drie tests bepalen of het prototype zijn doel haalt: aantonen dat het feedback-circuit werkt onder real-life condities. De **aparte Wizard-of-Oz controller-module** (XIAO ESP32-C3 + KY-040 encoder + ESP-NOW link met het handvat) maakt deze tests mogelijk zonder eerst een GPS-pipeline te moeten bouwen.

1. **Geïntegreerde wandeling met stok + handvat + microsignalen + kompas.** Tot nu toe werd het handvat los van de stok getest. Eindtest: de gebruiker stapt een onbekende route met de stok-tikken én het haptisch kompas in de handpalm én de drie microsignalen via de coin motor, terwijl de testleider de controller-module bedient en zo de richting bijstuurt. Vraag: kan de gebruiker alle drie de inputs parallel verwerken op natuurlijke wandelsnelheid?
2. **Indoor-validatie in een station.** Alle drie de blinde testers wezen spontaan op stations als doel-context. De huidige tests vonden plaats in residentiële omgevingen. Open: kan het systeem bij metro-style ruisniveau bruikbaar blijven, en blijft het haptisch kompas onderscheidbaar wanneer omgevingsgeluid de oren al belast?
3. **Cognitive load over een volledige wandeling.** Onze huidige tests waren 5 → 15 minuten. Open: kan de gebruiker 45+ minuten lang de hand-aandacht volhouden zonder dat de microsignalen of het kompas in de achtergrond verdwijnen?

Wat deze drie tests gemeen hebben, is dat ze de **integratie van alle inzichten samen onder real-life condities** meten, niet de individuele ontwerpkeuzes (die zijn al onderbouwd in Develop 1 → 3).

### Wat open blijft voor het beoogde eindproduct

Niet getest in dit project, vereist voor productie-deployment:

- **RTK GNSS-pipeline**: subscription en NTRIP-koppeling met FLEPOS / WALCORS, route-engine in smartphone-app, fail-over wanneer correcties uitvallen.
- **Obstakeldetectie**: keuze ToF vs ultrasoon, sensor-positionering, integratie met haptische taal (eventueel een nieuwe microinteractie M11/M12).
- **Productie-materialen**: overstap PLA → PA6 + TPE-overmold, herhalen CMF-tests met finale materialen.
- **BLE-app**: iOS / Android implementatie, koppeling met VoiceOver / TalkBack, route-input + monitoring.
- **Battery management**: low-power modes, batterij-feedback aan gebruiker via M9, langere autonomie (1500 → 2500 mAh).
- **Certificering**: ISO 9999 + nationale verkeerswetten + medische hulpmiddel-classificatie indien van toepassing.
- **Business case**: subsidie-traject (VLAIO, RIZIV), distributiemodel via Licht en Liefde / Brailleliga, sociale tariefkans op FLEPOS / WALCORS-licentie.

De vijf overkoepelende open onderzoeksvragen staan in de [Kritische reflectie](../README.md#kritische-reflectie).

---

[← Terug naar hoofdpagina](../README.md)

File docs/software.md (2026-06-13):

# Software-architectuur (SensePath)

Dit document beschrijft de **software-laag** van het SensePath-prototype: de
firmware van het handvat en de controller, en de telefoon-app. Voor de fysieke
bedrading en onderdelen, zie [bom.md](bom.md), [build_guide.md](build_guide.md)
en [wiring.md](wiring.md). De broncode staat in [`src/`](../src/).

> SensePath is een Wizard-of-Oz-prototype: de navigatie wordt nog door een
> begeleider/app gestuurd in plaats van door echte indoor-positionering. De
> software is zo gebouwd dat de gebruikerservaring (haptiek, kompas, audio,
> bediening) volledig echt aanvoelt.

---

## 1. Systeemoverzicht: drie apparaten

SensePath bestaat uit drie apparaten die samenwerken. Het **handvat** is het
centrale knooppunt: het stuurt de fysieke feedback aan én serveert de app.

```mermaid
graph LR
    C["Controller<br/>ESP32-C3<br/>encoder + afslagknop"]
    H["Handvat<br/>ESP32-S3<br/>servo, trilmotor,<br/>speaker, webserver"]
    P["Telefoon<br/>browser-app"]
    C -->|ESP-NOW draadloos| H
    P -->|WiFi / HTTP REST| H
    H -->|JSON kompas + instellingen| P
```

| Apparaat | Chip | Rol |
|---|---|---|
| **Handvat** | XIAO ESP32-S3 | Servo-kompas, trilmotor (haptiek), speaker (audio), WiFi-webserver die de app serveert |
| **Controller** | XIAO ESP32-C3 | Leest de rotary-encoder (richting) en de afslagknop; stuurt draadloos naar het handvat |
| **Telefoon** | (browser) | Toegankelijke app: bestemming zoeken, navigatie, live kompas, instellingen |

---

## 2. Het handvat (firmware, ESP32-S3)

Bestand: [`src/firmware/handle/main.cpp`](../src/firmware/handle/main.cpp).
Dit is het hart van het systeem. Het combineert vijf taken in één non-blocking
hoofdlus:

```mermaid
flowchart TD
    L([loop]) --> W[webserver bedienen<br/>app + twin]
    L --> K[ESP-NOW verwerken<br/>encoder en cues]
    L --> B[knop uitlezen]
    L --> S[servo veilig bijsturen]
    L --> Hp[haptiek-patroon stappen]
    L --> Au[audioclip afspelen<br/>indien aangevraagd]
```

**Belangrijkste onderdelen**

- **Servo-kompas** - vertaalt de encoderstand naar een hoek. De servo is
  gekalibreerd (begrensd µs-bereik) en heeft drie beveiligingen tegen
  oververhitting: auto-loskoppelen bij stilstand, een watchdog, en slew-rate
  -begrenzing (nooit springen).
- **Haptiek-engine** - speelt instelbare trilpatronen via de DRV2605L-driver.
  Werkt met realtime-aansturing zodat de coin-motor lange, voelbare pulsen geeft.
  De **sterkte-instelling** schaalt elke trilling.
- **Audio** - speelt ingebedde spraakclips (ETA, locatie) via I2S naar de speaker.
- **Webserver** - serveert de telefoon-app en de `/api/`-endpoints (zie §5).
- **Deep-sleep** - zet het toestel volledig uit (ook WiFi); wekken gebeurt met de
  knop en is een volledige herstart.

### Knop-gedrag (state machine)

De fysieke knop op het handvat herkent vier soorten druk. Wat elke druk doet, is
**instelbaar via de app** (zie §6); deep-sleep bij lang vasthouden blijft altijd
als veilige noodgreep bestaan.

```mermaid
stateDiagram-v2
    [*] --> Rust
    Rust --> Ingedrukt: knop omlaag
    Ingedrukt --> Kort: los binnen 0.4 s
    Ingedrukt --> Lang: los na 3 tot 6 s
    Ingedrukt --> DeepSleep: vasthouden 6 s of langer
    Kort --> Dubbel: 2e druk binnen 0.4 s
    Kort --> ActieKort: geen 2e druk
    Dubbel --> ActieDubbel
    Lang --> ActieLang
    ActieKort --> Rust: voert btn_short uit
    ActieDubbel --> Rust: voert btn_double uit
    ActieLang --> Rust: voert btn_long uit
    DeepSleep --> [*]: slaapt (wake = reboot)
```

---

## 3. De controller (firmware, ESP32-C3)

Bestand: [`src/firmware/controller/main.cpp`](../src/firmware/controller/main.cpp).
Een eenvoudig, robuust apparaat zonder eigen scherm of webserver:

- **Rotary-encoder** - bepaalt de richting/heading; via een transitietabel
  bounce-vrij uitgelezen.
- **Afslagknop** - 1 keer klikken = afslag rechts, 2 keer klikken = afslag links.
- **ESP-NOW-zender** - stuurt ~50x per seconde de encoderstand en eventuele
  afslag-cue naar het handvat.

De controller joint enkel de WiFi (zelfde netwerk als het handvat) om op het
juiste ESP-NOW-kanaal te komen; hij host verder niets.

---

## 4. De telefoon-app

Bron: [`src/app/index.html`](../src/app/index.html) (zie ook
[`src/app/README.md`](../src/app/README.md)). Eén HTML/CSS/JS-bestand dat het
handvat als web-app serveert - geen installatie nodig.

- **Toegankelijkheid-first** (het kernontwerp voor blinde gebruikers):
  - 1 tik = label voorlezen
  - 2 tikken = activeren
  - lang indrukken = hint
  - two-finger-swipe omhoog = hele scherm voorlezen
  - alle spraak via de Web Speech API (`nl-NL`)
- **Bestemming zoeken** via Google Maps (autocomplete, looproute, GPS-voortgang).
- **Digital twin** - een SVG-kompasnaald die live meedraait met de fysieke servo.
- **Instellingen** die het handvat aansturen (§6).

De app draait als een gewoon `index.html`-bestand. Voor de firmware wordt het
omgezet naar een C-string (`handle/webapp.h`) met
[`tools/html2header.py`](../src/firmware/tools/html2header.py); je kunt de app
ook los op je laptop testen met `src/app/mock_server.py`.

---

## 5. Communicatie

### 5.1 Controller -> handvat: ESP-NOW

ESP-NOW is een lichte, draadloze peer-to-peer-verbinding (geen router nodig voor
de link zelf). De controller stuurt de encoderstand; het handvat laat de servo
volgen. Cues (afslag links/rechts) gaan mee als een ophogend `cueId`, zodat een
verloren pakket niet leidt tot een gemiste of dubbele trilling.

### 5.2 Telefoon <-> handvat: WiFi + HTTP REST

De app praat met het handvat over gewone HTTP. De twee belangrijkste stromen:

```mermaid
sequenceDiagram
    participant E as Encoder
    participant H as Handvat
    participant A as Telefoon-app
    E->>H: ESP-NOW encoderstand
    H->>H: servo volgt, kompas beweegt
    loop elke 100 ms tijdens route
        A->>H: GET /api/servo
        H-->>A: hoek als JSON
        A->>A: kompas-naald draait mee
    end
```

**Endpoints op het handvat** (poort 80):

| Methode | Pad | Doel |
|---|---|---|
| GET | `/` | de app (HTML) |
| GET/POST | `/api/settings` | instellingen lezen / opslaan (NVS) |
| POST | `/api/settings/reset` | terug naar default |
| GET | `/api/servo` | huidige kompashoek (digital twin) |
| GET | `/api/pending` | knop-events ophalen (consume-on-read) |
| POST | `/api/trigger-effect` | trilling/sterkte-preview |
| POST | `/api/turn-preview` | afslag-patroon-preview |
| GET/POST | `/api/destinations`, `/api/route/start|stop`, `/api/state` | route/bestemmingen |

### 5.3 WiFi-presets en vindbaarheid

Beide ESP's proberen een **lijst voorkeursnetwerken** (presets, in `secrets.h`)
van boven naar beneden en verbinden met het eerste dat bereikbaar is. Zo werkt
het systeem op meerdere netwerken (bv. een telefoon-hotspot of de atelier-router)
zonder herflashen. Lukt geen enkel netwerk, dan opent het handvat zijn eigen
toegangspunt `SensePath` (de twin blijft werken, geen internet).

Belangrijk: beide ESP's moeten **dezelfde presetlijst** hebben, zodat ze op
hetzelfde WiFi-kanaal komen - ESP-NOW vereist dat. Het handvat is op het netwerk
bereikbaar via **mDNS** als `http://sensepath.local/`.

> Alleen 2,4 GHz (ESP32 kan geen 5 GHz). iPhone-hotspot: "Maximaliseer
> compatibiliteit" aanzetten.

---

## 6. Instellingen sturen het handvat aan

Elke wijziging in de app wordt als JSON naar het handvat gestuurd, daar
**persistent opgeslagen** (NVS-flash) en meteen toegepast.

```mermaid
flowchart LR
    A[Telefoon<br/>wijzigt instelling] -->|POST /api/settings| H[Handvat]
    H -->|bewaren| N[(NVS flash)]
    H -->|toepassen| FX[sterkte / afslag-patroon /<br/>knop-acties / audio]
    A -. preview .-> H
```

| Instelling | Effect op het handvat |
|---|---|
| **Sterkte** (laag/medium/hoog) | schaalt elke trilling (medium = standaard) |
| **Afslag rechts / links** | kies per richting een trilpatroon (1/2/3 trillingen, lang, ...) |
| **Korte / dubbele / lange druk** | wat de fysieke knop doet (spraak via speaker, noodhulp, slaapstand, ...) |
| **Audio** | poort voor de spraakclips op het handvat |
| **Noodcontact** | nummer dat de app belt bij de noodhulp-actie |

De spraak-acties van de knop komen **uit de speaker van het handvat** (clips),
niet via de telefoon. Bij het wisselen van een trilling-instelling speelt het
handvat meteen een **preview**, zodat je voelt wat je kiest.

---

## 7. Bestandsstructuur

```
src/
├── app/                      ← de telefoon-app
│   ├── index.html               de app (bewerk dit)
│   ├── mock_server.py           laptop-test zonder hardware
│   └── README.md
└── firmware/
    ├── handle/               ← handvat (ESP32-S3)
    │   ├── main.cpp
    │   ├── webapp.h             (auto-gegenereerd uit ../../app/index.html)
    │   ├── audio_clips.h        (auto-gegenereerd uit de WAV's)
    │   └── audio/
    ├── controller/           ← controller (ESP32-C3)
    │   └── main.cpp
    ├── shared/
    │   └── protocol.h          gedeeld ESP-NOW-berichtformaat
    ├── tools/
    │   ├── html2header.py       index.html  -> webapp.h
    │   └── wav2header.py        WAV-bestanden -> audio_clips.h
    └── platformio.ini          build-configuratie
```

> `secrets.h` (WiFi-wachtwoorden + Google-key) staat in elk firmware-onderdeel,
> is **gitignored** en wordt nooit meegecommit. Gebruik `secrets.h.example` als
> sjabloon.

---

## 8. Bouwen en flashen

Gebouwd met [PlatformIO](https://platformio.org/). Vanuit `src/firmware/`:

```bash
# Handvat (ESP32-S3) via USB flashen
pio run -e handle_usb -t upload

# Controller (ESP32-C3) via USB flashen
pio run -e controller_usb -t upload

# App gewijzigd? Eerst webapp.h opnieuw genereren:
python tools/html2header.py
```

De app los testen op de laptop (zonder hardware):

```bash
cd src/app && python mock_server.py     # http://localhost:8080/
```

---

## 9. Wat nog open is voor het eindproduct

- **Echte indoor-navigatie** in plaats van Wizard-of-Oz-aansturing.
- **Dynamische spraak** op het handvat (nu vaste opgenomen clips).
- **Native app** voor o.a. direct bellen zonder systeem-bevestiging (een web-app
  mag op iOS niet ongevraagd bellen).
- **Stroombeheer / batterij-indicatie** voor langdurig gebruik.

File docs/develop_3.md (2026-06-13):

# Develop 3, UX & Service Design (SensePath)

Dit document legt de concrete UX- en Service Design-beslissingen voor SensePath vast. Alle keuzes verwijzen expliciet naar het huidige prototype uit Develop 2: kunststof handvat met **hypothenar-kompasgleuf (H1-H5)**, één **in-handle vibratiemotor**, **IMU-gestuurde gripkalibratie**, **clip op bestaande witte stok**, gekoppelde **iOS-app**, en een **fail-safe herstart-flow**.

Visuele uitwerkingen:
- [Stakeholder map (PNG)](develop_3/img/stakeholder_map.png)
- [Customer Journey Map (PNG)](develop_3/img/customer_journey.png)
- [Service Blueprint (PNG)](develop_3/img/service_blueprint.png)

---

## 1. Emotie-matrix, wat we concreet doen in SensePath

Vier primaire emoties en vier anti-emoties. Per emotie: de concrete ontwerpingreep in het huidige prototype, en de onderbouwing (cursus-theorie + Discovery-quote).

### Primaire emoties

| Emotie | Concrete ingreep in SensePath | Onderbouwing |
|---|---|---|
| **Kalmte** | Default-toestand = *stilte*. Geen "alles-goed"-puls; correcte koers wordt niet bevestigd. Kompas-ticks alleen bij richtingcorrectie. Fade-in van elke trilling over 80 ms (geen abrupte aanzet). | Cursus *Attention* §3.2: aandacht is eindig, elk extra signaal kost cognitieve resources. Discovery-quote: *"in een station wil je niet overprikkeld worden, je bent al aan het zoeken met je oren"*. |
| **Vertrouwen** | **Confidence-puls**: voor elke afslag-crescendo geeft het systeem eerst een *heartbeat-pattern* (2 zachte pulsen @ 150 Hz) dat zegt "ik weet waar je bent". Als IMU-confidence < 70 %, valt de heartbeat weg, de gebruiker voelt meteen dat het systeem twijfelt. | Walter's piramide (*reliable* vóór *pleasurable*). Gulf of Evaluation (Norman): eerlijke status-communicatie > valse geruststelling. |
| **Autonomie** | **Manual-override gesture**: dubbele tap op het handvat ⇒ systeem wacht 5 s en geeft controle terug (gebruiker mag zelf beslissen, systeem niet dominant). Alle app-taal in de tweede persoon, nooit imperatief: *"wil je linksaf?"* i.p.v. *"ga links"*. | Martiniello et al. (2020): *user empowerment* en *symbolic meaning of autonomy* zijn top-2 stigma-verminderaars. Eyal: **self-reward** (mastery) versterkt retention. |
| **Discretie** | Handvat-kleur in **olijfgroen (olive green) mat** (geen "medische wit" ; gerealiseerd in het finale prototype). Geen LED's naar buiten zichtbaar. Geen audio-output op het handvat zelf; speech enkel via de telefoon-oortje-koppeling (bone conduction optioneel). Trillingen < 200 Hz en < 80 dB geluidslek. | Martiniello et al.: *visual analogy* (lijkt op mainstream tech) vermindert stigma. Discovery: *"ik wil niet dat mensen me aanstaren"*. |

### Anti-emoties

| Anti-emotie | Concrete vermijding | Onderbouwing |
|---|---|---|
| **Paniek** | Crescendo voor bocht start **5 m voor keuzepunt** met puls @ 1 Hz, groeit lineair naar 3 Hz op 1 m. Geen exponentiële versnelling, geen volumestijging. Maximale continue intensiteit gecapt op 60 % van motor-peak. | Cursus *Cognition* §3.2 *switching costs*: abrupte alerts dwingen reflective cognitie en verhogen foutkans. |
| **Infantilisering** | Geen "goed gedaan"-toon. App-stem is neutraal-volwassen (lage spraaksnelheid, geen jingles). Succesbevestiging = *warme lange puls* (500 ms fade-out), niet *"perfect!"*. Geen streaks, badges of "bestemmingen deze week"-metrics tenzij expliciet opgevraagd. | Cursus *Behavioral Design*: dark-pattern-risico bij persuasive design. Discovery: *"ik ben geen kind"*. |
| **Medicaliteit** | Materiaal: **glasvezelversterkt PA12** met soft-touch TPU-overmold, geen ABS-glans. Form-taal verwijst naar **outdoor / reizen** (vergelijk fietscomputer, hardloop-clip), niet naar ziekenhuisinstrument. Geen kruis-, plus- of medische pictogrammen. Verpakking in geperst karton, geen blisterverpakking. | Martiniello et al.: *visual analogy* met mainstream tech. Vaes (2014): *perceived stigma* volgt direct uit CMF-signalen. |
| **Faalgevoel** | Bij IMU-verlies heet het **"heroriënteren"**, niet "fout" of "signaal verloren". Fail-safe flow begint met een zachte ademende puls (0,5 Hz, 3 cycli) vóór eender welke instructie, geeft de gebruiker denktijd. App-tekst: *"we pakken dit samen op"*, niet *"er ging iets mis"*. | Cursus *Cognition* §3.1: attribution matters, de user-fout-attributie moet vermeden worden. Cognitive dissonance (Eyal): negatief gelabeld event verlaagt retention sterker dan neutraal event. |

---

## 2. Norman's drie lagen, concreet per laag voor SensePath

### 2.1 Visceral laag (eerste 3 seconden, non-visueel)

Wat de gebruiker voor het eerst voelt/hoort:

| Kanaal | Concrete spec | Waarom zo |
|---|---|---|
| **Gewicht** | 58-62 g (handvat + clip samen). P50-handvolwassene verwacht "telefoon-achtig compact". | Te licht (< 45 g) → *goedkoop gadget*; te zwaar (> 80 g) → belast de stokzwaai, Develop 1-feedback. |
| **Eerste tast-textuur** | Soft-touch TPU-overmold, shore 70A, matige micro-textuur (Ra 3-4 μm). | Cursus *Human Senses* §11.2: matte rubberized grip → "controle/comfort". Hard-glans = "cheap/slippery". |
| **Temperatuur aanvoelen** | Materiaalkeuze PA12 + TPU = lage warmtegeleiding → voelt **warmer** dan metaal bij eerste aanraking. | Koud metaal = "klinisch/instrument"; warm polymeer = "persoonlijk object". |
| **Clip-bevestiging** | Magnetische pre-alignering + mechanische *click* bij vergrendeling, hoorbaar **circa 45-55 dB** met lichte lage resonantie (2 kHz gedempt). | Intentional sound (cursus §11.3). Moet herkenbaar en kort zijn (< 80 ms), bevestigt installatie zonder app-check. |
| **Unbox-ritueel** | Magneetsluiting doos, reliëfletters "SENSEPATH" op deksel, katoenen linnen binnenhoes. Geen plastic folie, geen twist-ties. | Aanraakbaar = leesbaar voor blinde gebruiker. Premium-tactiel ≠ medisch. |

### 2.2 Behavioral laag (tijdens gebruik)

Dit is de Develop 2-laag, nu verfijnd via microinteractions, zie §3.

**Sleutelbeslissing die nu vastligt**: correcte-koers-toestand = **stilte** (niet een continue baseline-puls zoals overwogen in Develop 1). Dit bespaart 40 % motor-duty-cycle (batterij), vermindert habituation, en maakt event-signalen maximaal salient.

### 2.3 Reflective laag (zelfbeeld, verhaal)

| Reflectief doel | Concrete ingreep |
|---|---|
| "Ik ben iemand die moderne tools gebruikt voor mijn autonomie" | App noemt het product *"SensePath"*, niet *"navigatie-hulpmiddel"*. Mutualiteit-documentatie gebruikt de term **"mobility enhancer"**. |
| "Dit is gift-worthy" | Doos + handleiding in 3 talen, premium karton, QR-code-activatie via blindenvereniging geeft 6 maanden POI-premium, maakt het gift-ready zonder stigma. |
| "Ik deel dit met anderen zoals ik" | **Opt-in route-deling** met trainer of peer (via app). Geen publieke feed, geen likes, enkel 1-op-1 deling, waardig. |
| "Ik hou de controle" | Firmware-updates zijn **opt-in**, niet forced. Ruwe routedata staat lokaal, niet standaard in de cloud (GDPR + symbolische autonomie). |

---

## 3. Microinteractions, concrete specs (Saffer: trigger / rules / feedback / loops & modes)

Alle patronen gebruiken de **in-handle LRA-motor** (lineaire resonantie-actuator, 170-230 Hz) en het **IMU-gestuurde kompaselement** in de H1-H5 gleuf. Intensiteit uitgedrukt als percentage van motor-peak (PWM-duty).

### 3.1 Tabel microinteractions

> De feedback-kolom hieronder geeft *voorbeelden* van trilpatronen per moment. De definitieve patronen voor de drie MVP-prioriteiten (M4 bocht nadert, M6 afwijking van route, M9 batterij low) zijn pas na de Develop 3 user-test gekozen op basis van de voorkeursrangschikking door de deelnemers.

| # | Moment | Trigger | Regels | Voorbeeld feedback (wat de gebruiker voelt/hoort) | Loops & modes |
|---|---|---|---|---|---|
| M1 | **Route gestart** | App "Start route" bevestigd | Alleen als Bluetooth-link stabiel én IMU-kalibratie < 2 min geleden | 2 zachte pulsen LRA @ 180 Hz, 120 ms, 40 % int., interval 200 ms. Fade-in 80 ms. | Eén keer; geen loop. |
| M2 | **Confidence-heartbeat** (nieuw) | IMU + routepositie-confidence > 70 % | Elke 45 s in correcte-koers-toestand | 2 pulsen @ 150 Hz, 60 ms, 25 % int., interval 250 ms | Loop elke 45 s; stopt zodra confidence < 70 %. Mode: *ambient reassurance*. |
| M3 | **Correcte koers** | Default | Geen actieve feedback buiten M2 | **Stilte** (behalve heartbeat M2) | N/A. |
| M4 | **Bocht nadert** | Afstand tot keuzepunt = 5 m | Alleen 1× per keuzepunt | Crescendo: 5 pulsen @ 180 Hz, 100 ms elk, interval lineair van 1000 ms → 300 ms. Int. van 35 % → 60 %. Kompas tegelijk activeert richting (links/rechts) op hypothenar. | Start op 5 m, eindigt op 1 m. |
| M5 | **Bocht correct genomen** | IMU detecteert rotatie binnen 15° van verwacht pad binnen 3 s na M4 | Alleen na succesvolle M4 | Dubbele "tick": 2 pulsen @ 200 Hz, 40 ms, 50 % int., interval 80 ms | Eenmalig. Mode: *succesbevestiging* (zelfde patroon ook bij bestemming, kortere variant). |
| M6 | **Afwijking van route** | Off-path > 2 m gedurende > 4 s | Hysterese: moet 4 s aanhouden voor trigger | Ademende puls: 3 cycli @ 0,5 Hz, int. swing 15 % → 40 %. Kompas wijst naar dichtstbijzijnde ankerpunt. | Loop tot gebruiker terug < 1 m. |
| M7 | **Fail-safe actief** (IMU-verlies / GPS-gat / confidence < 40 %) | Systeem-onzekerheid | Onmiddellijk; overschrijft M2-M6 | Lange zachte trilling 800 ms @ 120 Hz, 30 % int., gevolgd door 1,5 s stilte. Optioneel (app-setting) korte spraak via oortje: *"heroriënteer, hou je stok stil"*. | Loop tot IMU-heroriëntatie bevestigd. Mode: *pause*, geen andere cues. |
| M8 | **Bestemming bereikt** | GPS/beacon-match + user-geometrie stabiel 3 s | Alleen op routeafsluiting | Warme lange puls: 1 puls @ 160 Hz, 600 ms, fade-in 200 ms, peak 70 %, fade-out 300 ms | Eenmalig. Zelfde patroon wordt "brand signature". |
| M9 | **Batterij low** (< 15 %) | Interval-contingent | Elke 10 min tot opgeladen | Drie korte ticks @ 220 Hz, 30 ms, 20 % int., interval 300 ms. Afwijkend hoog-frequent patroon ⇒ herkenbaar als "systeem-status", niet "route". | Loop elke 10 min. |
| M10 | **Clip-bevestiging op stok** | Mechanisch contact + IMU detecteert stok-orientatie | Bij fysieke installatie | Geen motor-feedback; enkel de mechanische *click* (intentional sound). App geeft audio-bevestiging *"klaar om te starten"*. | Eenmalig per sessie. |

### 3.2 Signature moments (de "herinnerbare" interacties)

Twee patronen zijn doelbewust uniek om *brand recognition* op te bouwen:
- **M8, warme lange puls bij aankomst**: enige 600 ms-puls in het hele systeem.
- **M4, crescendo voor bocht**: enige crescendo-patroon; alle andere events zijn statisch of pulserend.

### 3.3 Mapping emoties ⇄ microinteractions

- Kalmte → M3 (stilte) + M6 (ademend, laag-frequent).
- Vertrouwen → M2 (heartbeat) + M7 (eerlijk fail-safe).
- Autonomie → ontbreken van "push"-patroon buiten keuzepunten + dubbele-tap-override.
- Discretie → max 60 % intensiteit, geen audio uit handvat, LRA < 230 Hz (minder hoorbaar lek).

---

## 4. Stakeholder map

Vijf concentrische ringen, van kerngebruiker naar platform. Zie [develop_3/img/stakeholder_map.png](develop_3/img/stakeholder_map.png).

**Sleutelinzicht**: ring 3-4 (infrastructuur + institutioneel) levert ~40 % van de *value delivery* maar heeft nul fysiek contact met de gebruiker. Dit is de harde PSS-test: de service moet werken zonder dat de gebruiker die backstage-actoren ooit ontmoet.

---

## 5. Customer Journey Map

Vijf fases × vier rijen (touchpoints, actions, emotie-curve, pains/opportunities). Drie expliciete Moments of Truth gemarkeerd. Zie [develop_3/img/customer_journey.png](develop_3/img/customer_journey.png).

**Moments of Truth voor SensePath:**
- **MoT-1**: eerste 30 s na unboxing, visceral laag beslist over doorzetten of terugsturen.
- **MoT-2**: eerste fail-safe in publieke context, reflective laag beslist over vertrouwen op lange termijn.
- **MoT-3**: eerste keer zelfstandig routeafsluiting zonder hulp, autonomie-emotie wordt bevestigd of ondermijnd.

---

## 6. Service Blueprint

Vijf rijen × vier fases, met expliciete *line of interaction*, *line of visibility* en *line of internal interaction*. Zie [develop_3/img/service_blueprint.png](develop_3/img/service_blueprint.png).

**Kritieke afhankelijkheden die zichtbaar worden:**
- Zonder gebouwbeheerder-POI-data (backstage) werkt indoor wayfinding niet → noodzaak van B2G-model.
- Zonder mobiliteitstrainer-netwerk (frontstage) geen schaalbare onboarding → partnership met revalidatiecentra.
- Firmware- en mapping-updates zijn invisible maar bepalen lange-termijn vertrouwen.

---

## 7. Bronnen

Cursus: [IxD/Usability/UX](../Project%20theorie/SV_GO_IxD_Usability_UX_DesignPrinciples.md) · [Cognition](../Project%20theorie/SV_GO_Cognition.md) · [Human Senses & Interfaces](../Project%20theorie/SV_GO_HumanSenses&Interfaces.md) · [Social Interaction & Behaviour](../Project%20theorie/SV_GO_SocialInteraction&Behaviour.md) · [Evaluation Methods](../Project%20theorie/SV_GO_EvaluationMethods.md).

Extern: Norman *Emotional Design* (2004); Saffer *Microinteractions* (2013); Shostack (1984) *Service Blueprint*; Martiniello et al. (2020) *Aesthetics and perceived stigma of AT for visual impairment*; Eyal *Hooked* (2014); Fogg *Behavior Model*.

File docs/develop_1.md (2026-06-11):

# SensePath → Develop 1

[← Terug naar hoofdpagina](../README.md)

---

## Develop 1

### Doelstellingen

In de Develop 1-fase verschuift de focus van conceptvalidatie naar **functionele verfijning**. Het doel is om van concept naar een onderbouwde functionele architectuur te evolueren: onzekerheden wegnemen via gerichte onderzoeksvragen, het product ontleden in deelaspecten, en prototypevarianten bouwen en testen.

### Onderzoeksvragen

- Kan de gebruiker via een trilsignaal in het handvat correct en tijdig een afslag herkennen en uitvoeren (links, rechts, schuin)?
- Kan de gebruiker via continue kompasfeedback in het handvat een bocht volgen en op koers blijven?
- Hoe effectief is de combinatie van trilsignaal (event-cue) en kompasfeedback (continue koerscorrectie) bij een gecombineerd parcours?
- Hoe verhoudt de nauwkeurigheid (out-of-area proportion) zich tot vergelijkbare systemen in de literatuur, specifiek het Tactile Compass (Liu et al., CHI 2021)?
- Wat is de subjectieve ervaring (workload, vertrouwen, leerbaarheid) van de gebruiker bij elke conditie?

### Scenario & user flow (Norman's 7 stages of action)

Het kernscenario is: **van punt A naar punt B (bv. station → lokaal) wandelen met SensePath, zonder dat aandacht (auditief/mentaal) overbelast raakt.**

### Storyboard
<p align="center">
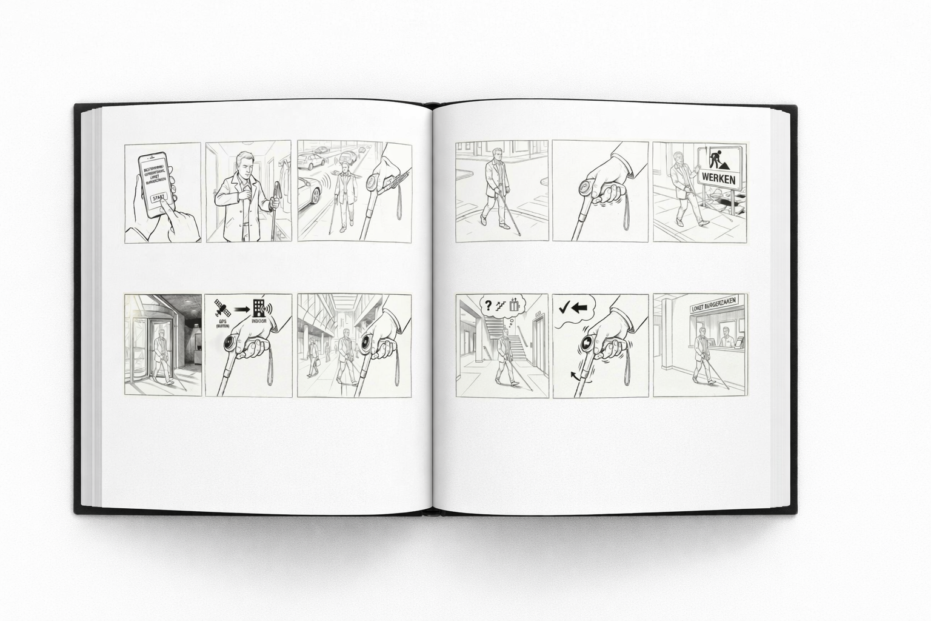
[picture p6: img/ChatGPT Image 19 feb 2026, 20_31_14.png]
  
</p>

De user flow werd geanalyseerd via Norman's 7 stages of action:

| Fase | Wat de gebruiker doet | Fricties & aandachtspunten |
|---|---|---|
| **Goal** | Veilig en zelfstandig aankomen, met rust/vertrouwen | Doel is breder dan "navigeren": ook veiligheid, vertrouwen, stress |
| **Plan** | Beslissen: SensePath gebruiken? Smartphone nodig? Haptiek-only of audio? | Te veel opties = keuzestress → overchoice-effect. Mental model mismatch: user verwacht "stok blijft stok" |
| **Specify** | "SensePath ON", route starten naar bestemming, mode kiezen | Onduidelijke signifiers: waar/hoe start ik? (knop, lang indrukken, dubbelklik) |
| **Perform** | Wandelen met stok + haptische richtingscue + evt. waarschuwing/confirmatie | Interactie mag niet "extra handelingen" vragen. Recall i.p.v. recognition = hogere load |
| **Perceive** | Haptiek voelen (primair), evt. audio horen, stokfeedback voelen | In echte context (wind, handschoenen, stress) kan haptiek minder onderscheidbaar zijn |
| **Interpret** | Cue → betekenis → actie (mentale mapping) | Ambiguïteit tussen soorten feedback. Mental model mismatch door verkeerde systeemimage |
| **Compare** | "Ben ik nog op koers? Voel ik me veiliger?" | Resultaat niet eenduidig te linken aan systeem. Emotie en stress domineren de evaluatie |

### User flow

<p align="center">
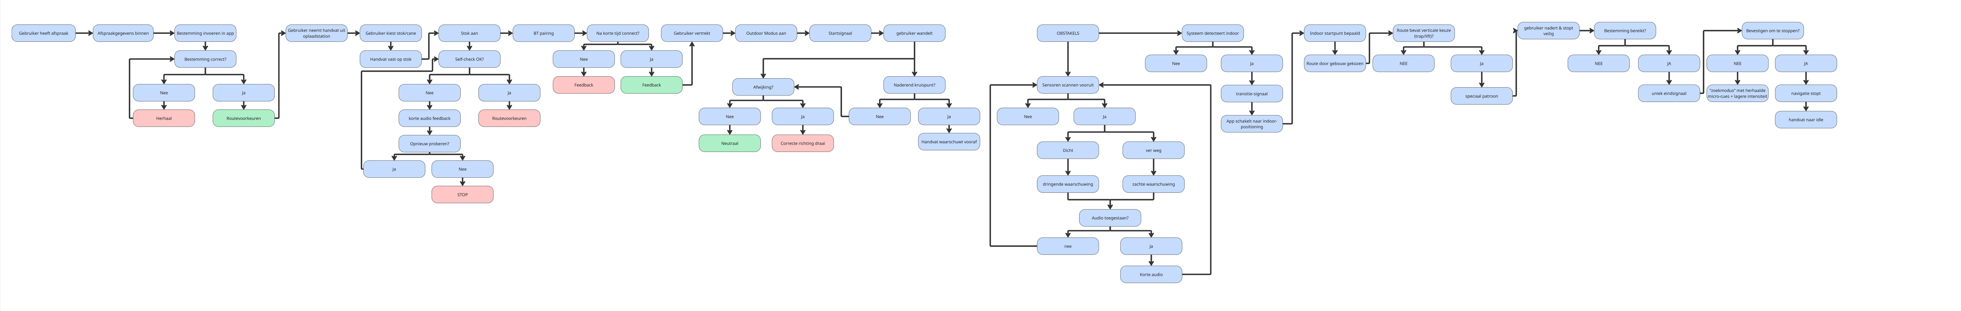
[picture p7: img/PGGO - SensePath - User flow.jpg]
User flow SensePath
  
</p>

### Functionele breakdown

Het product werd ontleed in 8 functionele deelgebieden:

**1) Locatie instellen + vertrekken**
Persoon krijgt afspraakgegevens, zet bestemming in app (spraak/typ), bevestigt routekeuze, pakt handvat van oplaadstation, klikt/lockt op stok, handvat gaat aan (auto-on), app koppelt (BT) en geeft "klaar om te vertrekken" (korte haptische ping).

**2) Buiten wandelen: "kompas"-feedback (draaiend bolletje in handpalm)**
Systeem bepaalt startpositie + richting (GPS/kompas/IMU), handvat geeft startsignaal, bolletje draait naar "juiste looprichting", persoon voelt bol-oriëntatie in handpalm en corrigeert lichaam/looplijn. Bij GPS drift/urban canyon → systeem schakelt naar "lage zekerheid" patroon.

**3) Kruispunt: links/rechts instructie via trillmotoren (duim/middelvinger)**
Systeem herkent aankomend kruispunt (route-data + positie), handvat "waarschuwt vooraf", persoon vertraagt/zoekt veilig punt. Afslaaninstructie: trilling duim = rechts, trilling middelvinger = links. Persoon bevestigt (optioneel): knop/knijp/voice "ok".

**4) Obstakel: detectie + audiofeedback**
Sensoren scannen vooruit (hoogte/afstand), systeem detecteert obstakel, classificatie "urgentie": ver weg → zachte waarschuwing, dichtbij/snel → dringende waarschuwing. Audiofeedback start (via telefoon of speaker/bone conduction). Zodra obstakel voorbij: audio stopt + korte haptische "clear".

**5) Gebouw binnen: overgang outdoor → indoor**
Systeem merkt "GPS weg / signaalpatroon verandert" of detecteert ingang (geo-fence), handvat geeft transitie-signaal, app schakelt naar indoor positioning (BLE/Wi-Fi/UWB/QR-kaart). Kalibratie: "sta 1 seconde stil" (haptische vraag) om heading/IMU te resetten.

**6) Binnen: preciezere navigatie door het gebouw**
Systeem bepaalt indoor startpunt (ingang node), route door gebouw wordt gekozen (corridors, deuren, obstakels, toegankelijkheid). Persoon wandelt rechtuit: bolletje haptiek voor koers (subtwieler dan buiten). Turn-instructie via duim/middelvinger (zoals kruispunt, maar korter).

**7) Trappen en liften: verticale navigatie**
Systeem detecteert "verticale keuze punt" (trap/lift in route), handvat geeft speciaal patroon. Trap = ritmisch oploppend patroon, lift = lang-kort-lang. Persoon nadert trap/lift en stopt op veilige positie. Systeem geeft keuze/advies (toegankelijkheid). Trap-flow: waarschuwing → tempo-haptiek voor op/af → "einde trap" signaal.

**8) Aankomst op locatie**
Systeem herkent "bestemming bereikt", handvat geeft duidelijk eindsignaal (uniek patroon), systeem geeft "precise cue": exacte deur/desk. Persoon verifieert bestemming (tast naambordje, vraagt hulp, luistert). Navigatie stopt automatisch of na bevestiging ("stop"). Handvat gaat naar idle (energie besparen).

### Productarchitectuur (I/O)

<p align="center">
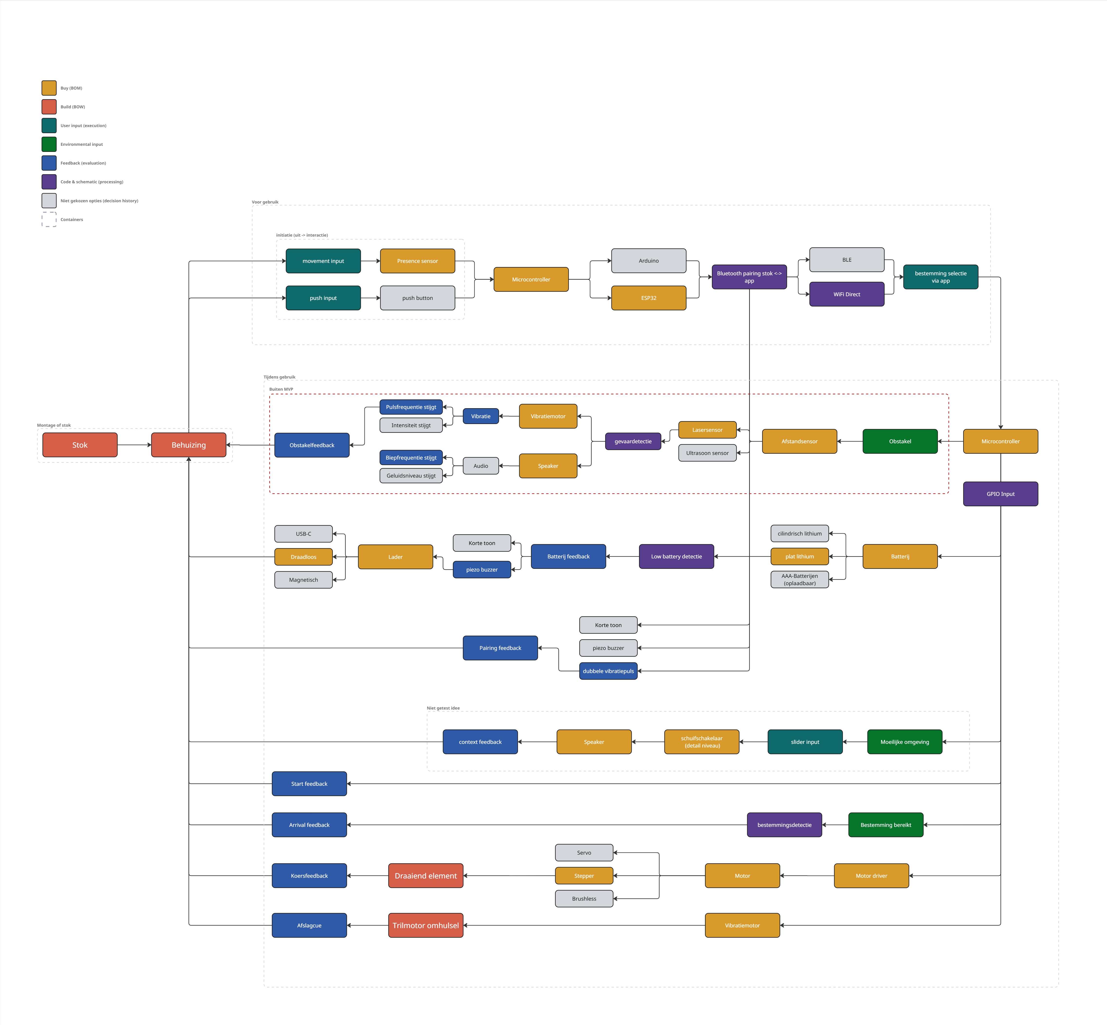
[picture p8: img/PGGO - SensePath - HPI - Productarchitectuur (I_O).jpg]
Productarchitectuur I/O diagram
  
</p>

De technische architectuur is opgebouwd rond drie lagen:

**Voor gebruik (initiatie + interactie):**
- Input: movement input (presence sensor) + push input (push button)
- Processing: microcontroller (Arduino/ESP32) met BLE of WiFi Direct pairing stok ↔ app
- Output: bestemmingselectie via app

**Tijdens gebruik:**
- Montage op stok → behuizing → obstakeldfeedback (pulsfrequentie/intensiteit stijgt)
- Vibratie (vibratiemotor) + audio (speaker) als outputmodaliteiten
- Gevaarsdetectie via lasersensor + ultrasoon sensor → afstandsmeting → obstakel → microcontroller
- Koersfeedback via draaiend element (servo/stepper/brushless motor → motor driver)
- Afslagcue via trilmotor omhulsel (vibratiemotor)

**Energiemanagement:**
- Batterij: lithium (cilindrisch/plat) of AAA oplaadbaar
- Opladen: USB-C / draadloos / magnetisch
- Low battery detectie → batterij feedback (korte toon / piezo buzzer)

### MVP-definitie

De MVP wordt gedefinieerd als de minimale set functies die moet werken om de kernwaarde van het concept aan te tonen: dat een gebruiker via haptische feedback binnenshuis van A naar B begeleid kan worden, met minimale smartphone-interactie tijdens het stappen.

**Essentieel voor proof of interaction:**
1. Start/stop van guidance
2. Continue haptische koersfeedback (recht lopen)
3. Turn cue op beslissingspunten (links/rechts) met duidelijke mapping
4. Aankomst/stop signaal (afscheidsritueel) zodat het systeem "sluit"
5. Basis statuszekerheid (minimaal: "guidance is aan")

**Niet essentieel voor proof of interaction:**
- Automatische herberekening
- Obstakeldetectie (los van navigatie)
- Uitgebreide contextbeschrijvingen
- Geavanceerde personalisatie in real time

**MVP-gate: speaker ja of nee**
Speaker wordt als experimentele variant binnen de MVP-test behandeld:
- Variant A: haptiek-only (baseline)
- Variant B: haptiek + minimale audio (alleen status of arrival, niet continu)
- Variant C: audio-first benchmark (zoals veel bestaande systemen)

### Morfologische matrix

<p align="center">
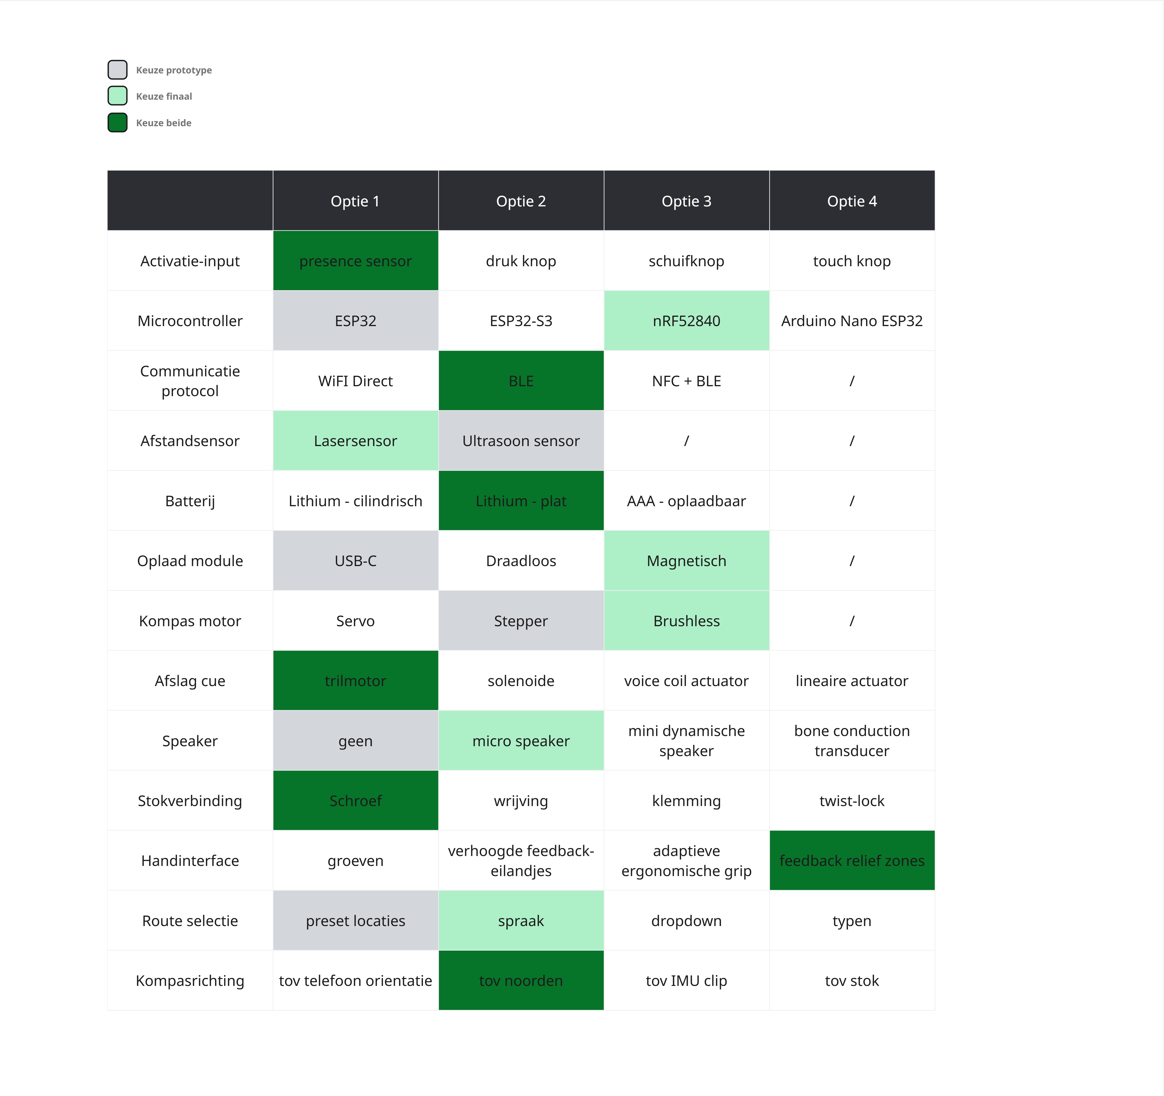
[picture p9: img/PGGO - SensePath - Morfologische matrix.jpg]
Morfologische matrix met functionele deelaspecten en oplossingsvarianten
  
  <br/><em>Morfologische matrix → de deelfuncties (input, feedback, montage, voeding) en hun varianten waaruit het Develop 1 ontwerp gecombineerd is.</em>
</p>

De morfologische matrix werd gebruikt om per functieblok een afweging te maken tussen wat vandaag het meest geschikt is voor het prototype, wat later het meest geschikt lijkt voor het eindproduct, en welke keuzes in beide fasen overeind blijven.

Volgens de legende betekent:
- **grijs** = keuze voor het prototype
- **lichtgroen** = keuze voor het eindproduct
- **donkergroen** = keuze voor beide

### Interpretatie van de keuzes

De matrix toont dat we voor het **prototype** vooral kozen voor oplossingen die snel testbaar, robuust en technisch haalbaar zijn binnen een iteratief ontwikkelproces. De nadruk ligt daar op het kunnen valideren van de kerninteractie en het betrouwbaar opzetten van experimenten.

Voor het **eindproduct** verschuiven de keuzes meer naar verfijning, compactheid, integratie en gebruikskwaliteit. Hier ligt de focus sterker op comfort, subtiliteit van feedback, toegankelijkheid en een meer afgewerkte gebruikerservaring.

De keuzes die voor **beide** gelden, tonen welke principes voor ons conceptueel fundamenteel zijn. Het gaat daarbij vooral om de basis van de interactie: hoe het systeem geactiveerd wordt, hoe de gebruiker begeleid wordt, hoe feedback wordt gegeven en welke referentiestructuur het systeem gebruikt om richting betekenisvol te maken.

### Interactieblokken & informatiehiërarchie

De MVP-interacties zijn opgedeeld in 5 blokken met oplopende pressure:

**A. Voor vertrek** (low pressure, smartphone toegestaan): route/bestemming selecteren, handle bevestigen, grip checken.

**B. Start guidance**: actie via fysieke input of gesture (knop duidelijk en robuust, gesture vereist filtering tegen accidental triggers).

**C. Tijdens wandelen** (high pressure, geen smartphone): continue koersfeedback voelen (background), omgeving scannen met stok (parallelle primaire taak), micro-correcties uitvoeren.

**D. Beslissingspunten**: turn cue detecteren en interpreteren (event), actie uitvoeren (links/rechts), korte bevestiging na turn (optioneel).

**E. Stop of aankomst**: arrival/stop cue (closure), guidance stopt en wordt stil.

**Informatiehiërarchie:**
- Background info: koersfeedback (mag niet opdringerig zijn)
- Event info: turn cue (hoog belang, korte duidelijke cue)
- Fail/status info: alleen wanneer nodig (bv. guidance aan/uit)

### Prototypes

Er werden twee prototypevarianten gebouwd op basis van de morfologische matrix:

**Prototype 1: Vibratie (afslagcue)**
3D-geprint handvat met drie trilmotoren (duim, wijsvinger, middelvinger) aangestuurd via ESP32 en een Wizard-of-Oz controller-app. De wizard triggert op het juiste moment links/rechts/rechtdoor signalen.

**Prototype 2: Kompas (koersfeedback)**
3D-geprint handvat met een draaiend bolletje in de handpalm dat continue richtingsfeedback geeft. De wizard stuurt de kompasrichting aan op basis van de gewenste looprichting.

<p align="center">
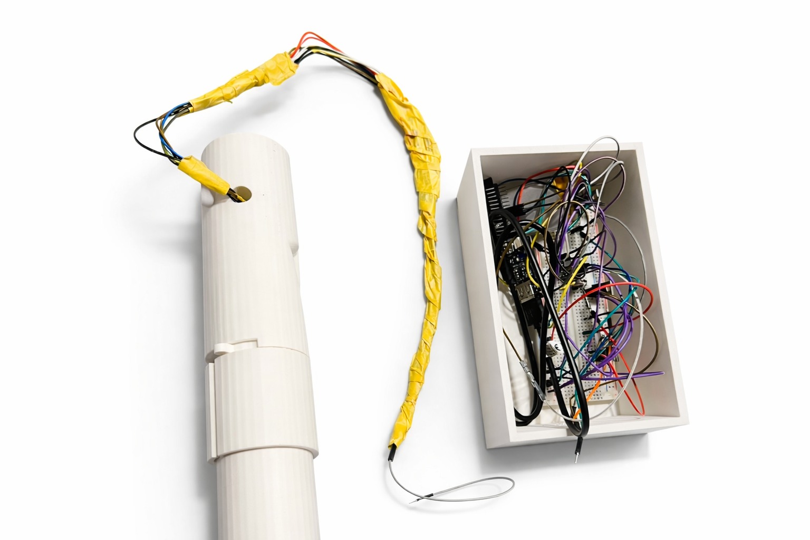
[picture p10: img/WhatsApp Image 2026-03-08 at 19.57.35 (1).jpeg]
Develop 1 prototype: trilmotor-handvat (afslagcue)
  
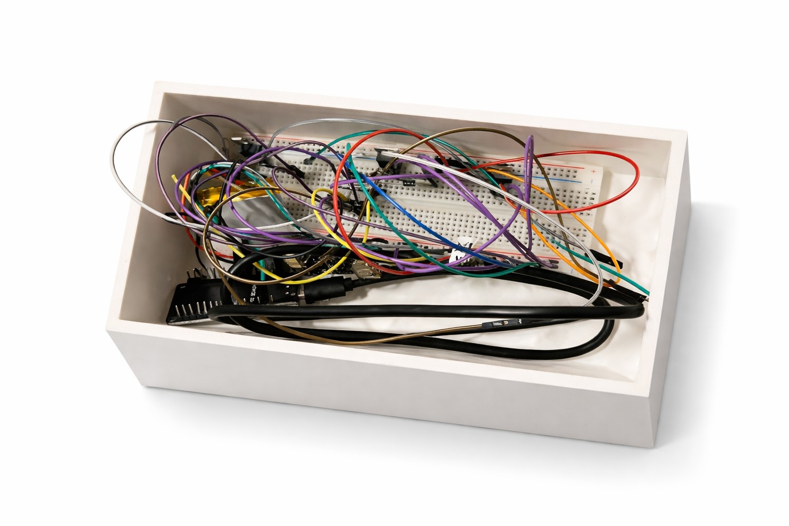
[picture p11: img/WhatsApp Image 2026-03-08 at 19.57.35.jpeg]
Develop 1 prototype: kompas-handvat met draaiend bolletje
  
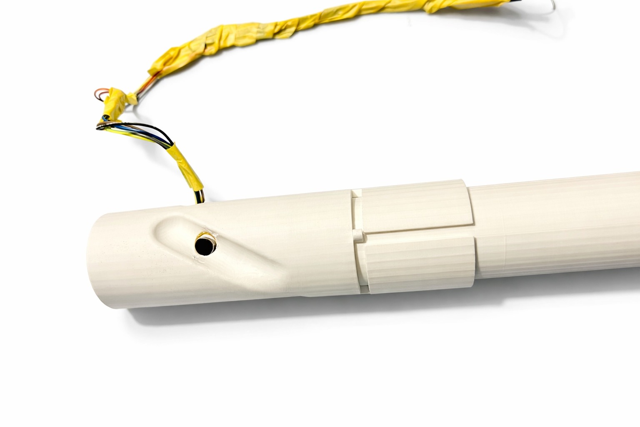
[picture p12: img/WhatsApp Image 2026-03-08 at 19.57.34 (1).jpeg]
Develop 1 prototype: ESP32-controller en bedrading van trilmotoren
  
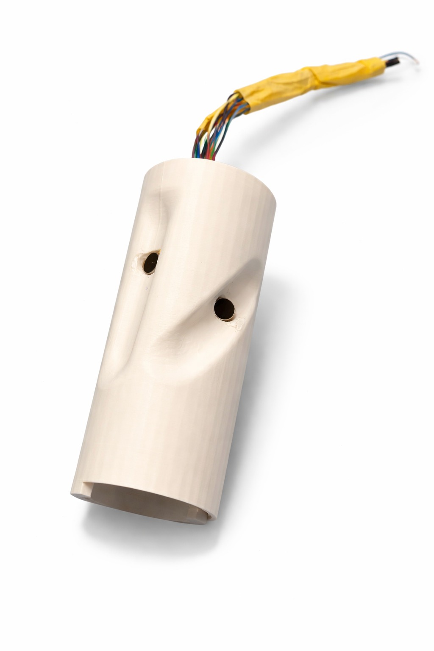
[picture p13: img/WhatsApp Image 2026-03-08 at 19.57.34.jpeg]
Develop 1 prototype: testopstelling met handvat aan witte stok
  
  <br/><em>Develop 1 prototypes (N=5) → Prototype 1 (vibratie-afslagcue) en Prototype 2 (continu kompas). Beide via Wizard-of-Oz aangestuurd.</em>
</p>

### User testing

**Sample (N=5):**

| Naam | Leeftijd | Relevantie | Locatie | Datum |
|---|---|---|---|---|
| Mario | 52 | Verloor zicht op 18-jarige leeftijd | Licht en Liefde | 04/03/2026 |
| Rory | 55 | Ernstig slechtziend | Licht en Liefde | 04/03/2026 |
| Herman | 65 | Blind sinds geboorte | Licht en Liefde | 06/03/2026 |
| Milo | 20 | Ziend (controle) | Thuis | 08/03/2026 |
| Milos | 20 | Ziend (controle) | Thuis | 08/03/2026 |

**Protocol:** Introductie & leerfase → Test 1 (kompas) → Interview & subjectieve scores → Test 2 (vibratie) → Interview & subjectieve scores → Test 3 (gecombineerd) → Reflectie. Alle tests via Wizard-of-Oz op een afgetaped parcours (60cm breedte).

### Test 1: Bocht via kompasfeedback

De wizard biedt continue feedback via het draaiende kompasbolletje in het handvat.

> *"Ik denk dat het zelfs zou lukken om niet buiten het pad te gaan."*

**Key findings:**
- **Grip bepaalt interpretatie**: Verschillende grip = links/rechts omgekeerd. Handoriëntatie is cruciaal.
- **Palmsensatie is zwak**: Meerdere deelnemers voelden het bolletje nauwelijks.
- **Ergonomie onvoldoende**: Handvat past niet bij elke hand. Bolletje is verkeerd gepositioneerd.
- **Rechtdoor lopen werkt**: Goede resultaten bij rechtdoor; bochten zijn moeilijker.
- **Winter = probleem**: Handschoenen en dikke jassen blokkeren de sensatie.

**Benchmark vergelijking Test 1:**

| Metric | Tactile Compass (Liu et al.) | SensePath |
|---|---|---|
| SIZ (% stappen in zone) | 92,6% | 83,78% |
| Leerbaarheid (1-7) | 6,67 | 5,67 |
| Soepelheid (1-7) | 6,06 | 5,50 |
| Cognitieve belasting (1-7) | 5,22 | 3,67 |
| Bereidheid (1-7) | 6,39 | 5,33 |
| Vertrouwen (1-7) | n.v.t. | 5,33 |

### Test 2: Afslag via trilsignaal

De wizard stuurt trilsignalen op het juiste moment via de controller-app.

> *"Die trilmotoren, dat ging wel goed."*
> *"Het voelde beter, minder concentreren dan het balletje."*

**Key findings:**
- **Vingertoppen voelen het best**: "Daar zitten de voelers."
- **Afslaan werkt goed**: Richtingssignalen worden snel begrepen en aangeleerd.
- **Rechtdoor is moeilijker**: Zonder continu signaal drijven gebruikers af.
- **Bevestigingssignaal nodig**: Gebruikers willen feedback dat ze rechtdoor lopen.
- **Niet te veel signalen**: "Begin niet met zevenhonderdachtendertig verschillende signalen."
- **Sensorpositie problematisch**: Links past goed = rechts past slecht, en omgekeerd. Handgrootte speelt een rol.

**Benchmark vergelijking Test 2:**

| Metric | Tactile Compass (Liu et al.) | SensePath |
|---|---|---|
| SIZ (% stappen in zone) | 92,6% | 79,85% |
| Leerbaarheid (1-7) | 6,67 | 6,50 |
| Soepelheid (1-7) | 6,06 | 6,33 |
| Cognitieve belasting (1-7) | 5,22 | 4,67 |
| Bereidheid (1-7) | 6,39 | 6,33 |
| Vertrouwen (1-7) | n.v.t. | 6,00 |

### Test 3: Gecombineerd parcours

Kompas (continue koersfeedback) + vibratie (afslagcue) samen op hetzelfde parcours.

> *"Ik ben wel onder indruk van deze keer."*
> *"Het was beter dan ik had verwacht."*

**Key findings:**
- **Vibratie interfereert met kompas**: Twee systemen tegelijk aflezen op één hand is moeilijk.
- **Ergonomie is de bottleneck**: Huidig prototype laat geen eerlijke evaluatie toe.
- **Concept heeft potentieel**: Vibratie als aankondiging + kompas voor koerscorrectie is logisch.
- **Hogere cognitieve belasting**: Scores dalen vergeleken met individuele tests.
- **Herpositionering bolletje**: Suggestie: naar de knokkels of hiel van de hand i.p.v. de palm.
- **Audio als back-up**: Speaker/bluetooth voor wanneer vibraties niet waarneembaar zijn.

**Benchmark vergelijking Test 3:**

| Metric | Tactile Compass (Liu et al.) | SensePath |
|---|---|---|
| SIZ (% stappen in zone) | 92,6% | **97,52%** |
| Leerbaarheid (1-7) | 6,67 | 6,00 |
| Soepelheid (1-7) | 6,06 | 4,67 |
| Cognitieve belasting (1-7) | 5,22 | 3,00 |
| Bereidheid (1-7) | 6,39 | 4,33 |
| Vertrouwen (1-7) | n.v.t. | 3,00 |

### Develop 1 conclusies

- **Vibratie is intuïtiever** dan kompas voor discrete navigatie-events (afslagen).
- **Kompas biedt superieure koersbewaking** maar lijdt onder perceptuele ambiguïteit.
- De **gecombineerde conditie scoorde het hoogst op nauwkeurigheid** (97,52% SIZ) maar het laagst op subjectieve ervaring.
- **Ergonomie is geen bijzaak**; het is de primaire confound in de data.
- SensePath houdt stand tegen de **Tactile Compass benchmark** onder moeilijkere condities (met stok, video-observatie i.p.v. OptiTrack, Wizard-of-Oz i.p.v. automatisch).
- **90% van alle fouten** is te wijten aan wizard-timing; bij automatisering worden minder fouten verwacht.
- Gebruikers memoriseren onbewust het pad over de drie tests heen, wat een confound vormt voor de SIZ-scores.

### Kritische reflectie Develop 1

De drie test-runs leverden zowel signaal als ruis op, en de scheidslijn ertussen bepaalt welke conclusies dragend zijn voor het verdere ontwerp.

Het sterkste signaal is de **convergentie tussen test 1 en test 2 op snellere foutcorrectie**: dat patroon bevestigt onze hypothese dat de gebruiker via herhaalde blootstelling een mentaal model opbouwt van de feedbacktaal. Implicatie voor Develop 2: de leerfase moet expliciet in de UX zitten (oefenmodus, kalibratie), niet impliciet via gebruik.

De **convergentie over test 1, 2 en 3 op path learning** is daarentegen een confound dat onze meetstrategie ondermijnt: deelnemers onthouden het parcours onbewust, waardoor SIZ-scores na test 2 niet meer de feedback meten maar het geheugen. Implicatie: Develop 2 en 3 moeten ofwel met verschillende parcours werken, ofwel het leereffect expliciet rapporteren.

Het meest design-kritische inzicht is dat **90% van de fouten herleidbaar is tot wizard-timing**, niet tot gebruikersgedrag. Dat betekent dat het huidige fout-percentage geen ondergrens is van wat het systeem kan, maar een bovengrens van wat Wizard-of-Oz kan meten. Implicatie: voor de finale validatie hebben we een geautomatiseerd systeem nodig dat dezelfde test reproduceerbaar uitvoert ; deze open vraag draagt door naar de [Deliver](deliver.md)-fase.

Tot slot beïnvloedt **de testomgeving de cognitieve belasting** in een mate die we niet vooraf controleerden. Implicatie voor Develop 2: omgevingscontext meenemen als variabele in de test-opzet, niet als ruis.

---

[← Terug naar hoofdpagina](../README.md) · [Volgende fase → Develop 2](develop_2.md)

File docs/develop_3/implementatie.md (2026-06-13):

# SensePath Develop 3, concrete implementatielijst

Drie sporen: **App**, **Elektronica** en **Hardware**. Per item een kolom "Bron" die zegt uit welk idee, welke theorie of welke emotie/microinteraction de keuze komt. Geen uitleg, geen visuals, enkel wat gebouwd wordt.

---

## 1. App (iOS, VoiceOver-compatibel)

| # | Implementatie | Bron |
|---|---|---|
| A1 | Audio-onboarding die de gebruiker door de grip-kalibratie leidt | Norman behavioral + grip-dependency uit Dev 1 |
| A2 | Grip-kalibratie-routine: gebruiker houdt handvat 10 s vast, IMU registreert natuurlijke oriëntatie | Dev 2 conclusie over mental mapping safeguard |
| A3 | Neutraal-volwassen TTS-stem, lage spraaksnelheid, geen jingles | Anti-emotie "infantilisering" |
| A4 | App-teksten in tweede persoon ("wil je linksaf?"), nooit imperatief | Primaire emotie "autonomie" |
| A5 | Fail-safe UI heet "heroriënteren", niet "fout" of "signaal verloren" | Anti-emotie "faalgevoel" |
| A6 | Instelling om feedback-intensiteit (laag/medium/hoog) aan te passen | Martiniello stigma factor "customization" |
| A7 | Instelling om audio-modus aan te zetten als secundaire laag (Rory: "audio still works better") | Dev 2 Test 3 feedback |
| A8 | Route starten met één bevestigingsknop, grote hit-area | Fitts' law |
| A9 | Dubbele-tap op handvat triggert 5 s "override"-modus waarin app wacht | Primaire emotie "autonomie" + micro-interactie manual override |
| A10 | Maandelijks tekstueel routerapport (opt-in, geen badges/streaks) | Anti-emotie "infantilisering" |
| A11 | 1-op-1 route-deling met trainer of familielid (geen publieke feed) | Reflective laag, waardigheid |
| A12 | Firmware-updates uitsluitend opt-in, nooit forced | Reflective laag "ik hou de controle" |
| A13 | Route-data standaard lokaal opgeslagen, cloud-sync opt-in (GDPR) | Reflective laag + GDPR |
| A14 | Bluetooth-link-indicator en IMU-kalibratie-leeftijd zichtbaar | Microinteractie M1 trigger rule |
| A15 | Confidence-waarde uit routing-engine leesbaar voor haptische laag | Microinteractie M2 heartbeat |
| A16 | Batterij-drempel-notificatie (via BLE characteristic) | Microinteractie M9 |
| A17 | POI-melding via dubbele app-tap ("lift defect", "werken") | Customer journey fase D |

---

## 2. Elektronica & firmware

| # | Implementatie | Bron |
|---|---|---|
| E1 | Eén LRA-motor (170 tot 230 Hz) in de handle | Dev 2 D6.10 + D6.6 |
| E2 | IMU (accelerometer + gyroscoop + magnetometer) voor griporiëntatie | Dev 2 D6.9 |
| E3 | BLE 5.x module voor koppeling met iOS-app | Dev 2 prototype-flow |
| E4 | Li-ion cell, USB-C laadpoort, vervangbare module | Customer journey fase E (graceful degradation) |
| E5 | Microcontroller met vibratie-patroonbibliotheek voor M1 tot M10 | Microinteractions-tabel |
| E6 | PWM-duty-cycle control voor intensiteit per patroon (25% tot 70%) | Microinteractions-tabel |
| E7 | Fade-in 80 ms op elke trilling, fade-out waar gespecificeerd | Primaire emotie "kalmte" |
| E8 | Confidence-heartbeat-loop (M2): elke 45 s, 2 pulsen, auto-stop als confidence < 70% | Microinteractie M2 |
| E9 | Crescendo-generator (M4): 5 pulsen, 1 Hz naar 3 Hz, 35% naar 60% intensiteit | Microinteractie M4 |
| E10 | Hysterese op off-path detection (4 s aanhouden voor M6) | Anti-emotie "paniek" + M6 |
| E11 | Fail-safe override (M7): onderbreekt alle andere patronen | Microinteractie M7 |
| E12 | IMU-drift-detectie, triggert grip-fallback-signifier | Dev 2 signifier 3 |
| E13 | Outside/inside detectie (licht of druk of RSSI-gebaseerd), triggert transitie-signifier | Dev 2 signifier 2 |
| E14 | Tap-detectie via IMU voor dubbele-tap override-gesture | App A9 |
| E15 | Capacitieve of mechanische aan/uit-knop op handle | Algemene hardware-logica |
| E16 | Audio-passthrough via BLE naar telefoon-oortje (geen speaker op handle) | Primaire emotie "discretie" |
| E17 | Batterij-voltage-read, low-threshold trigger voor M9 | Microinteractie M9 |
| E18 | Sensor-module pauzeert kompas tijdens vibratiecue (D6.5) | Dev 2 figure-ground contrast |
| E19 | Max continue motor-intensiteit softwarematig gecapt op 60% | Anti-emotie "paniek" |
| E20 | Servo of stappenmotor voor fysieke kompasdeflectie (volle rotatie + gradual return) | Dev 2 D6.4 |

---

## 3. Hardware prototype

| # | Implementatie | Bron |
|---|---|---|
| H1 | Handvat-behuizing, glasvezelversterkt PA12 | Anti-emotie "medicaliteit" |
| H2 | Soft-touch TPU-overmold, shore 70A, micro-textuur Ra 3 tot 4 µm | Visceral laag "tast-textuur" |
| H3 | Olijfgroen (olive green) mat als hoofdkleur | Primaire emotie "discretie" |
| H4 | Handvat-dimensies binnen P25 tot P75 ANSUR II (middle 50%) | Dev 2 D6.8 |
| H5 | Kompasgleuf met compass-element op positie H1 (hypothenar) | Dev 2 D6.1 |
| H6 | Sferisch kompaselement, medium protrusiehoogte | Dev 2 D6.2 + D6.3 |
| H7 | Verwisselbare compass module (default + winter-variant voor handschoenen) | Dev 2 D6.7 |
| H8 | Geen vibratiemotoren op individuele vingerposities | Dev 2 D6.10 |
| H9 | Schroefverbinding naar bestaande witte stok (compatibel met meerdere stokmodellen) | README + hero-render |
| H10 | Geen externe LED's of visuele indicatoren op de handle | Primaire emotie "discretie" |
| H11 | Geen audio-speaker op de handle | Primaire emotie "discretie" |
| H12 | Totaalgewicht handvat + clip-module binnen 58 tot 62 g | Visceral laag "gewicht" |
| H13 | Vervangbare batterijmodule, toegankelijk zonder speciaal gereedschap | Customer journey fase E (graceful degradation) |
| H14 | USB-C laadpoort standaard, geen propriëtaire dock | Fogg ability-laag (reduce physical effort) |
| H15 | Aan/uit-knop taktiel onderscheidbaar (ander oppervlak dan omringend handvat) | Signifier-principe |
| H16 | Geen kruis-, plus-, of medische pictogrammen op behuizing of verpakking | Anti-emotie "medicaliteit" |
| H17 | Verpakking in geperst karton, geen blister of plastic folie | Anti-emotie "medicaliteit" + unbox-ritueel |
| H18 | Reliëfletters "SENSEPATH" op doos-deksel, tastbaar | Visceral laag "unbox-ritueel" |

---

## Legenda van bronnen

- **Dev 1 / Dev 2**: resultaten en design requirements uit `reports and protocols/Report_SensePath_Devolop_1.pdf` en `Rapport_Dev2_PDF.pdf`.
- **Primaire emotie**: kalmte, vertrouwen, autonomie, discretie (zie develop_3.md §1).
- **Anti-emotie**: paniek, infantilisering, medicaliteit, faalgevoel.
- **Microinteractie Mx**: zie develop_3.md §3, Saffer-tabel.
- **Norman laag**: visceral, behavioral, reflective (develop_3.md §2).
- **Martiniello (2020)**: stigma en aesthetics van AT voor visueel beperkten.
- **Fogg / Eyal / Walter**: behavioral design, hook-model, pyramid of needs.

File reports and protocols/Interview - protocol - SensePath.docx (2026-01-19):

## Interview protocol

### Project informatie

Projectnaam: Spatial experiences for visually impaired populations

Spatial experiences for visually impaired populations is een onderzoeks- en ontwerptraject gericht op het verbeteren van de zelfstandigheid en levenskwaliteit van blinde en ernstig slechtziende personen. We benaderen visuele beperking in de brede zin – niet enkel mobiliteit, maar alle aspecten van het dagelijks leven (vb. huishouden, werk, vrije tijd, sociale interacties). Door middel van gebruikersgerichte interviews willen we inzichten verwerven in de uitdagingen, routines, frustraties en dromen van deze doelgroep, om nieuwe technologische hulpmiddelen of diensten te kunnen ontwerpen die aansluiten bij hun noden. De interviews kaderen in de discovery fase van het ontwerpproces: eerder voor dit interview is reeds benchmarking door technologie-scouting en concurrentieanalyse uitgevoerd naar bestaande oplossingen (zoals GPS-navigatieapps voor buitengebruik die indoor navigatie niet oplossen).

Interviewer: Sam Piryns ( sam.piryns@ugent.be ), Student Industrieel Ingenieur Industrieel Ontwerpen

### Doelstelling en kadering

Het doel is begrijpen hoe blinde en slechtziende personen hun dagelijks leven ervaren, welke hulpmiddelen ze gebruiken, waar pijnpunten zitten en waar zij kansen zien voor innovatie. De interviews zijn exploratief en vertrekken vanuit hun verhalen en prioriteiten.

Onderzoeksfase: Vroege probleemexploratie; resultaten voeden de definitie van design requirements en vervolgonderzoek.

Relevantie: De maatschappij is sterk visueel georiënteerd; informatie en oriëntatie zijn vaak niet (voldoende) toegankelijk. Bestaande hulpmiddelen helpen, maar kennen beperkingen, zeker binnenshuis. Dit onderzoek vertrekt bij de gebruikerservaringen zelf.

### Respondenten

Volwassenen die blind of ernstig slechtziend zijn (bij voorkeur volledig blind of langdurig sterk beperkt zicht). We bevragen eindgebruikers, geen mantelzorgers of experts voor dit protocol.

De interviews duren 15-20 min en worden afgenomen van 18/10/2025 - 25/10/2025

Steekproefomschrijving (N = 3)

pseudonym | respondent type | interview datum | interview locatie
Stijn | Jobcoach, 35 jaar, blind van geboorte | 18/10/2025 | BrailleTech
Toon | /, 36 jaar, blind van geboorte | 18/10/2025 | BrailleTech
Pieterjan | Ambtenaar, 34, blind van geboorte | 18/10/2025 | BrailleTech

# Onderzoeksvragen

Hoe ervaren blinde en slechtziende personen hun dagelijks leven, welke obstakels en frustraties komen zij daarin tegen, en op welke manieren (technologisch of anderszins) zou hun zelfstandigheid en levenskwaliteit verbeterd kunnen worden?

Deelvragen:

· Welke dagelijkse routines, activiteiten en gewoontes hebben zij, en welke aspecten verlopen vlot of moeizaam?

· Welke hulpmiddelen en technologieën gebruiken zij momenteel? Hoe effectief zijn die en waar schieten ze tekort?

· Welke pijnpunten of taken veroorzaken frustratie of afhankelijkheid, en waar zouden zij extra hulp of innovatie willen?

· Hoe navigeren zij in publieke binnenruimtes (gemeentehuis, musea, school, pretpark…) en welke knelpunten ervaren zij?

· Hoe vragen zij hulp (omstaanders, personeel, Be My Eyes, andere diensten) en hoe ervaren zij die interacties?

· Wat is hun eerste reactie op het concept van slimme indoor navigatie met QR-codes? Welke wensen/voorwaarden hebben zij?

· Welke eigen suggesties of ideeën hebben zij voor nieuwe hulpmiddelen of diensten?

# Overzicht van de discussiegids en tijdsinschatting

- Deel 1 – Introductie (2’)
- Deel 2 – Voorstelling Interviewee (3’)
- Deel 3 – Dagelijkse leven & routine (4’)
- Deel 4 – Huidige hulpmiddelen en strategien (3’)
- Deel 5 – Uitdagingen & behoeften (3’)
- Deel 6 – Navigatie & hulp vragen (3’)
- Deel 7 - Conceptfeedback QR-navigatie (3’)
- Deel 8 - Afsluiting

# Discussiegids

## Introductie (2’)

Bedankt voor je deelname aan dit onderzoek.

Ik zal starten met het project en mezelf kort voor te stellen.

Ik ben Sam Piryns en ik studeer aan de universiteit Gent campus Kortrijk met afstudeerrichting industrieel ingenieur industrieel ontwerpen.

Ik volg Industrieel Ingenieur – Industrieel Ontwerpen aan de UGent (campus Kortrijk). In het vak Gebruiksgericht Ontwerpen leren we via kwalitatieve interviews en veldwerk om noden van gebruikers te begrijpen en daaruit ontwerpvereisten af te leiden. Ik voer dit gesprek dus vanuit een mensgerichte ontwerpbenadering, met aandacht voor privacy, ethiek en correcte weergave van jouw verhaal.

De uitdaging die ik onderzoek is breed: waar botsen blinde en ernstig slechtziende mensen in het dagelijks leven op, en waar kan innovatie het meeste waarde bieden? Dat kan gaan van bewegen en oriënteren tot kleding/styling, koken, werk, vrije tijd en sociale interacties. Een subthema waar ik zelf benieuwd naar ben, is oriëntatie in publieke gebouwen, maar dit interview blijft open voor alles wat jij belangrijk vindt.

Met dit interview wil ik zicht krijgen op wat vlot gaat, wat moeilijk is, welke hulpmiddelen je gebruikt, en waar nog kansen liggen. Jouw input helpt ons om aannames te vermijden en ontwerpbeslissingen te baseren op echte ervaringen. Daarom is jouw deelname belangrijk: jij bent expert van je eigen leven en kan scherp aangeven wat er wél werkt en wat niet.

Ik stel open, verkennende vragen en moedig verhalen/voorbeelden aan. Denk aan vragen zoals “Welke oplossingen gebruik je al, wat werkt en wat niet?”, “Wat zou beter kunnen en waarom?”, en “In welke context gebeurt dat?” We verkennen meerdere domeinen (bijv. styling/kledij, koken, werk/school, vrije tijd, relaties) zodat er onverwachte opportuniteiten kunnen opduiken.

Jouw inzichten vertalen we naar concrete ontwerpvereisten, prioriteiten en succescriteria (wat moet een oplossing minimaal kunnen om echt te helpen). Zo zorgen we dat mogelijke concepten later relevant, haalbaar en wenselijk zijn voor mensen zoals jij, in echte situaties—niet enkel in theorie.

Ik ben erg benieuwd naar jouw inzichten en ervaringen. Er zijn geen juiste of foute antwoorden. Ik ben gebaat bij jouw oprechte feedback rond de topics die we zullen behandelen.

Ik wil zeker nog onderstrepen dat alles wat straks in het gesprek aan bod komt in absolute confidentialiteit behandeld wordt. We zijn als studenten aan de Ugent namelijk gebonden aan de Europese privacy richtlijnen. Voor de synthese met de inzichten en aanbevelingen worden individuele meningen sowieso ook geanonimiseerd. Je naam zal met andere woorden niet gekoppeld worden aan specifieke uitspraken. Een meer gedetailleerde beschrijving van onze intenties, verwerking van gegevens, en algemeen beleid kan je nalezen in de ‘Informed Concent’. Voor we van start kunnen met het interview, heb ik jouw expliciet akkoord nodig met dit document.

Ten slotte, had ik je ook graag gevraagd of ik straks dit gesprek mag opnemen met een voice recorder, om ons gesprek te kunnen herbeluisteren wanneer de analyse wordt gemaakt. Uiteraard wordt deze opname niet gedeeld met derden, en verwijderd na afloop van het project. Als u hiermee akkoord gaat, stel ik voordat we het interview beginnen.

## ----------------------------[invullen informed consent & start recording] ----------------------------

## Contextuele vragen

## Deel 2 – Voorstelling Interviewee (3’)

- Kunt u uzelf kort voorstellen? (Bijvoorbeeld: wat is uw naam, uw leeftijd en wat doet u in het dagelijks leven?)
  - Probe: Wat zou ik moeten weten over u om een goed beeld van u te krijgen?
- Kunt u iets vertellen over uw zicht of eventuele visuele beperking?
  - Probe: Hoe zou u uw zicht omschrijven – heeft u nog restvisus of bent u volledig blind?
  - Probe: Sinds wanneer heeft u deze visuele beperking en is dat geleidelijk of plotseling ontstaan?

## Deel 3 – Dagelijkse leven & routine (4’)

- Kunt u mij meenemen door een typische dag in uw leven? (Vanaf het opstaan tot aan het naar bed gaan – wat zijn uw dagelijkse activiteiten?)
  - Probe: Hoe begint u ’s ochtends uw dag en welke routine hebt u daarbij?
  - Probe: Welke activiteiten onderneemt u op een normale dag, bijvoorbeeld werk, studie of hobby’s?
- Hoe verplaatst u zich doorgaans gedurende de dag?
  - Probe: Gebruikt u meestal de bus, trein, taxi of gaat u te voet? Hoe regelt u dit praktisch?
  - Probe: Kunt u een voorbeeld geven van hoe u naar een vertrouwde bestemming gaat, zoals de supermarkt of uw werk?
- Woont u zelfstandig, en hoe organiseert u uw dagelijkse routine thuis?
  - Probe: Krijgt u hulp van iemand bij huishoudelijke taken of doet u alles zelf?
  - Probe: Zijn er vaste rituelen of hulpmiddelen die u elke dag gebruikt om uw dag soepel te laten verlopen?

## Deel 4 – Huidige hulpmiddelen en strategieën (3’)

- Welke hulpmiddelen gebruikt u momenteel om uw weg te vinden of te navigeren?
  - Probe: Maakt u gebruik van een witte stok of geleidehond?
  - Probe: Gebruikt u technologische hulpmiddelen, bijvoorbeeld een GPS-navigatie app op uw smartphone of speciale apps voor blinden/slechtzienden?
- Welke strategieën past u toe als u naar een nieuwe of onbekende plek gaat?
  - Probe: Bereidt u zich van tevoren voor door bijvoorbeeld routeinformatie op te zoeken of iemand om aanwijzingen te vragen?
  - Probe: Neemt u soms contact op met diensten of mensen (bijv. belt u iemand op, of gebruikt u een app als Be My Eyes) voor hulp onderweg?
- Hoe gaat u om met onverwachte situaties tijdens het navigeren?
  - Probe: Wat doet u bijvoorbeeld als een vertrouwde route ineens niet begaanbaar is (door wegwerkzaamheden, omleidingen, etc.)?
  - Probe: Heeft u een back-up plan of alternatieve aanpak wanneer u merkt dat u de weg kwijt bent?

## Deel 5 – Uitdagingen & behoeften (3’)

- Tegen welke grootste uitdagingen loopt u aan in het dagelijks leven vanwege uw beperkte zicht?
  - Probe: Kunt u een paar concrete voorbeelden geven van lastige situaties, bijvoorbeeld op straat, in het openbaar vervoer of in een gebouw?
  - Probe: Hoe voelt u zich in zulke situaties en hoe lost u ze meestal op?
- Welke behoeften of wensen heeft u om uw dagelijkse leven gemakkelijker te maken op het gebied van mobiliteit en navigatie?
  - Probe: Is er iets waarvan u denkt: “Als ik dit (hulpmiddel of oplossing) had, zou het veel schelen in mijn onafhankelijkheid”?
  - Probe: Wat zou u het liefst verbeterd of veranderd zien in uw omgeving of in bestaande hulpmiddelen om beter te kunnen navigeren?
- Als u één uitdaging kon laten verdwijnen, welke zou dat zijn?
  - Probe: Waarom juist deze uitdaging, en hoe zou uw leven veranderen als die was opgelost?

## Deel 6 – Navigatie & hulp vragen (3’)

- Kunt u een recent voorbeeld beschrijven van een situatie waarin u de weg moest vinden op een onbekende plek?
  - Probe: Hoe heeft u zich op die situatie voorbereid voordat u op pad ging?
  - Probe: Wat deed u ter plekke – gebruikte u een hulpmiddel of heeft u iemand om hulp gevraagd?
- Hoe gaat u er meestal mee om als u tijdens het navigeren ergens niet uitkomt?
  - Probe: Probeert u eerst zelf het probleem op te lossen? Zo ja, hoe (bijvoorbeeld rondlopen, oriëntatiepunten zoeken)?
  - Probe: Vraagt u gemakkelijk hulp aan voorbijgangers als u iets niet kunt vinden? Kunt u een situatie noemen waarin u dit deed?
- Hoe ervaart u het om hulp te vragen aan anderen bij het navigeren?
  - Probe: Zijn er drempels of aarzelingen voor u om vreemden aan te spreken voor hulp? Waarom wel of niet?
  - Probe: Hoe reageren mensen meestal als u om hulp vraagt, en wat voor effect heeft dat op uw ervaring?
- Maakt u gebruik van hulpmiddelen om op afstand hulp te krijgen bij navigatie?
  - Probe: Bijvoorbeeld, belt u weleens familie/vrienden om u te laten navigeren, of gebruikt u apps met een hulplijn/videoverbinding?
  - Probe: In welke situaties schakelt u zulke hulp in, en hoe effectief vindt u dit?

## Deel 7 – Navigatie in publieke ruimtes (3–5’)

In dit deel wil ik graag dieper ingaan op hoe navigatie en oriëntatie in publieke gebouwen vandaag in de praktijk verlopen voor mensen met een visuele beperking.
We focussen op ruimtelijke oriëntatie, hulpmiddelen in de omgeving (zoals leibanden en geleidelijnen) en de ervaring van toegankelijkheid binnen gebouwen zoals gemeentehuizen, stations, scholen, ziekenhuizen of musea.

### Hoofdvraag

Hoe ervaart u het navigeren in publieke gebouwen? Wat werkt goed, en waar loopt het nog vaak mis?

Verdiepende vragen (probes)

Oriëntatie en informatievoorziening

- Hoe vindt u doorgaans uw weg in onbekende gebouwen? Probe: Gebruikt u vaste strategieën, hulpmiddelen of vraagt u meestal hulp aan personeel?
- Hoe duidelijk vindt u de bewegwijzering, auditieve aanwijzingen of architecturale opbouw (zoals akoestiek, materiaalverschillen, of lichtcontrasten)? Probe: In welke gebouwen heeft u zich ooit écht goed kunnen oriënteren, en wat maakte dat mogelijk?

Leibanden en geleidelijnen

- Wat is uw ervaring met tactiele leibanden of geleidelijnen (vloermarkeringen met voelbare ribbels of contraststroken)? Probe: Wanneer helpen ze écht om zelfstandig te navigeren? Probe: In welke situaties werken ze minder goed of worden ze zelfs verwarrend?
- Zijn er specifieke omgevingen waarin u vindt dat leibanden cruciaal zijn en andere waar ze minder zinvol zijn? Probe: Denkt u dat ze overal aanwezig moeten zijn, of enkel op strategische plaatsen (zoals kruispunten, liften, of ingangen)?
- Hoe belangrijk is het dat leibanden logisch aansluiten op belangrijke punten (zoals balies, liften, trappen of toiletten)? Probe: Heeft u situaties meegemaakt waarin dit niet goed gebeurde? Wat was het gevolg?

Auditieve en tactiele signalen

- Hoe waardevol vindt u auditieve signalen (zoals piepjes bij liften of gesproken richtingaanwijzers)? Probe: Zijn er omstandigheden waarin zulke signalen storend worden, bijvoorbeeld door omgevingslawaai?
- Zou u een voorkeur hebben voor auditieve feedback, trillingen/haptische signalen, of een combinatie van beide? Waarom?

Interactie met omgeving en mensen

- Hoe gemakkelijk vindt u het om in een nieuw gebouw hulp te vragen of begeleiding te vinden? Probe: Is er voldoende herkenbaarheid bij personeel of duidelijke punten waar men hulp kan vragen?
- Wat maakt volgens u het verschil tussen een toegankelijk gebouw en een complex gebouw om in te navigeren? Probe: Zijn er specifieke ontwerpelementen (zoals akoestiek, vloertextuur, hoogteverschillen) die dit beïnvloeden?

Verbeteringen en toekomstvisie

- Welke verbeteringen zou u graag zien op het vlak van ruimtelijke toegankelijkheid in publieke gebouwen? Probe: Gaat het volgens u vooral om betere infrastructuur (zoals geleidelijnen en herkenbare structuren) of om betere informatievoorziening (zoals plattegronden, begeleiding, sensoren…)?
- Als u één aspect mocht kiezen dat het grootste verschil zou maken voor zelfstandige navigatie, wat zou dat zijn? Probe: Kunt u een concreet voorbeeld geven van hoe dat er in de praktijk zou uitzien?

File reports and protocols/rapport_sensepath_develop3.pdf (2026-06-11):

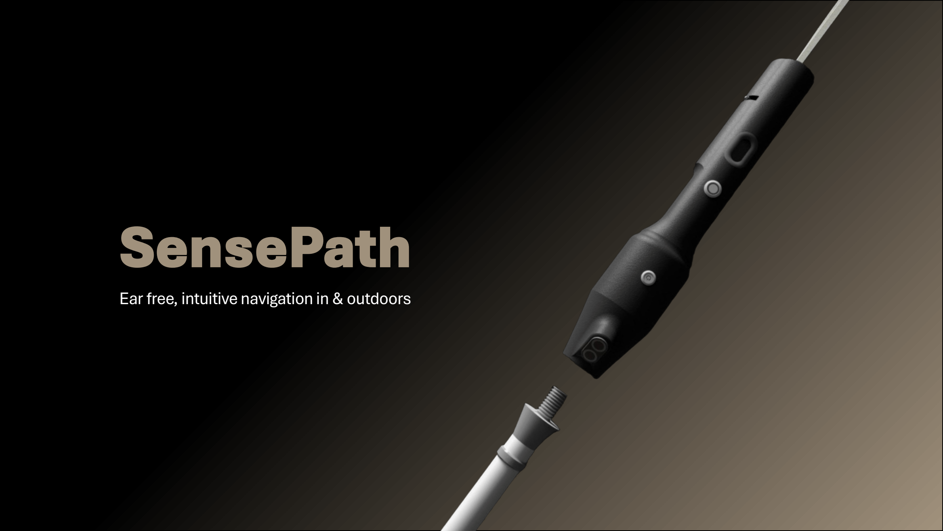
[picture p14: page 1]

# SensePath

Ear free, intuitive navigation in & outdoors

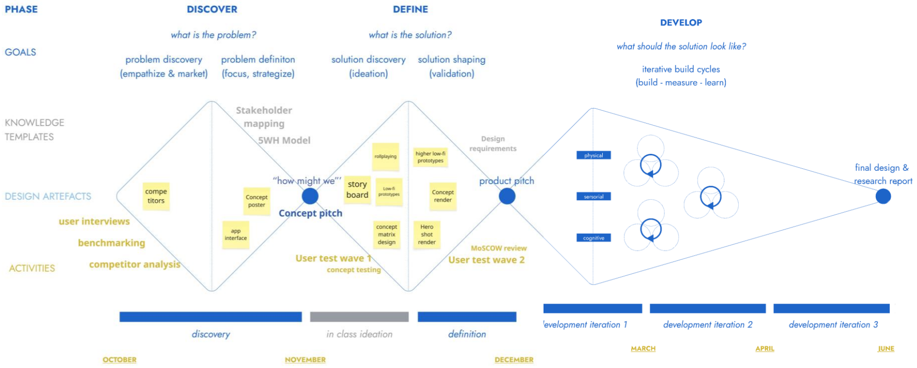
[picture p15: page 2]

Prototypes

# Develop

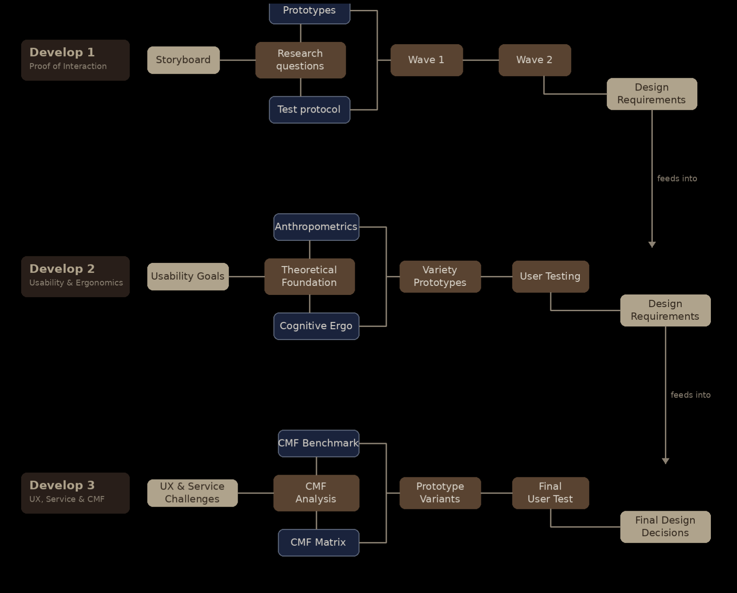
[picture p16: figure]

# Methodology

# Develop 3

# Methodology

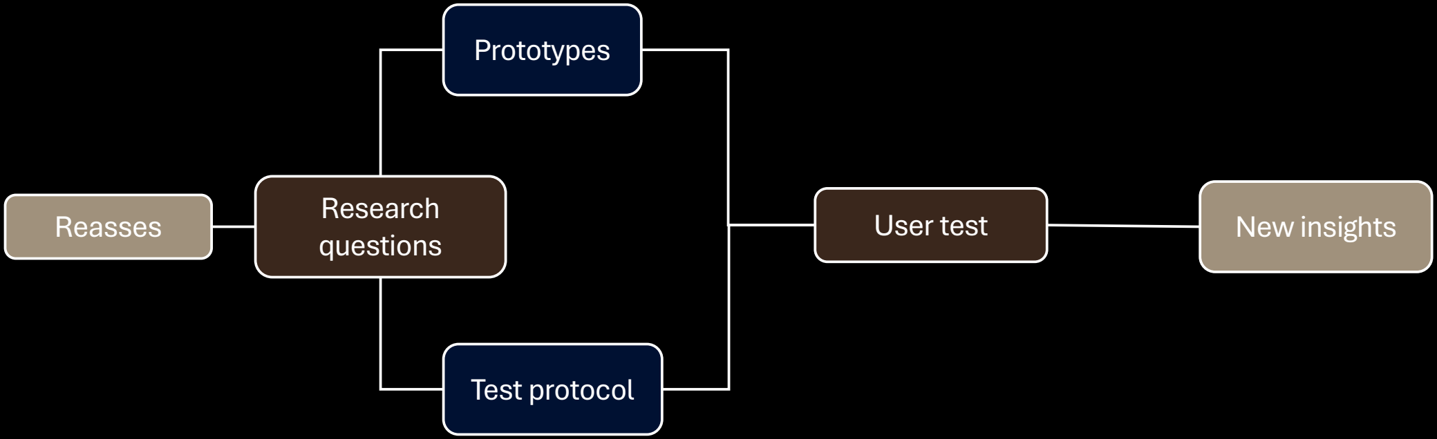
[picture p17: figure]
Reasses; Prototypes; User test; Test protocol; Research; questions; New insights

# Research Questions

- Which set of vibration patterns (max. three to four signals via a single vibration motor) is sufficiently distinguishable and intuitive to communicate an obstacle, route deviation, and announcement of a turn without cognitive overload?
- At what moment before a turn does the user want to receive a preparatory vibration (expressed in steps, meters, or seconds)?
Do users desire a single neutral directional announcement signal in combination with the compass, or an explicit distinction between left and right in the pattern?
Which handle material (hard standard cane, softer compressible handle, cork element) is preferred in terms of tactility and usability in all weather conditions?
Which color choice for the handle aligns with the need for contrast for the visually impaired and external visibility in public spaces?
Does the perceived cognitive load and trust in a real-life context (traffic, pedestrians, guidelines, level differences) differ significantly from the lab setting in Develop 2?
Do users desire personal customizability of vibration patterns and announcement distances, or does a fixed default setting suffice?

# Goal

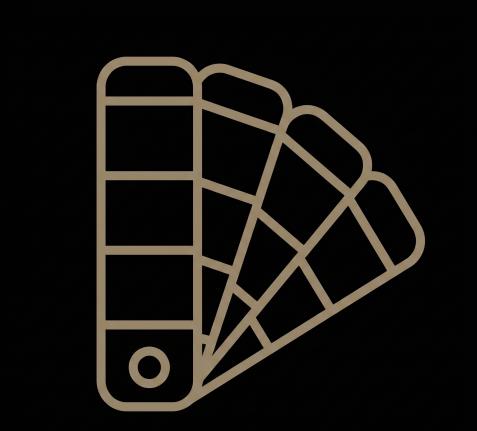
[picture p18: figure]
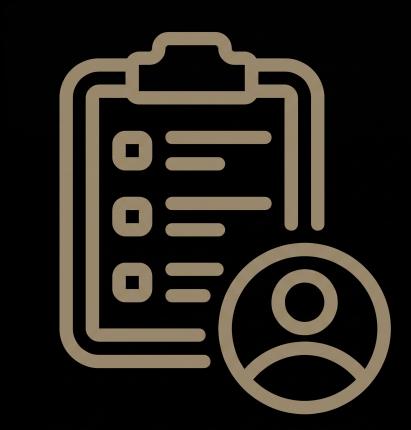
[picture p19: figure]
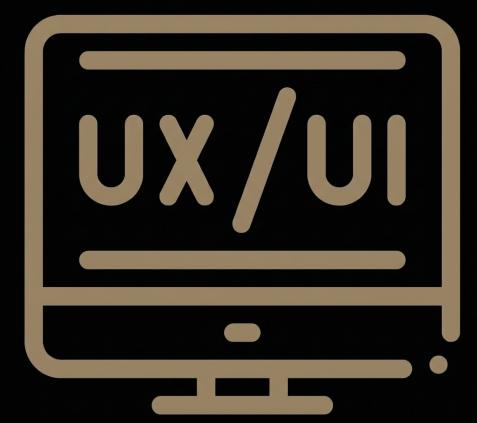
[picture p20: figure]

CMF Deepdive | Assess UX | Final user test

# UX test

# Prototype

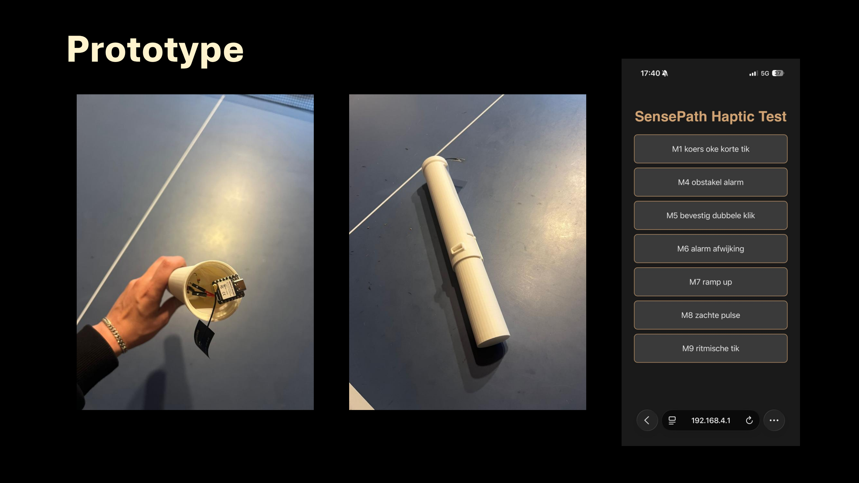
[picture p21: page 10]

# Workflow

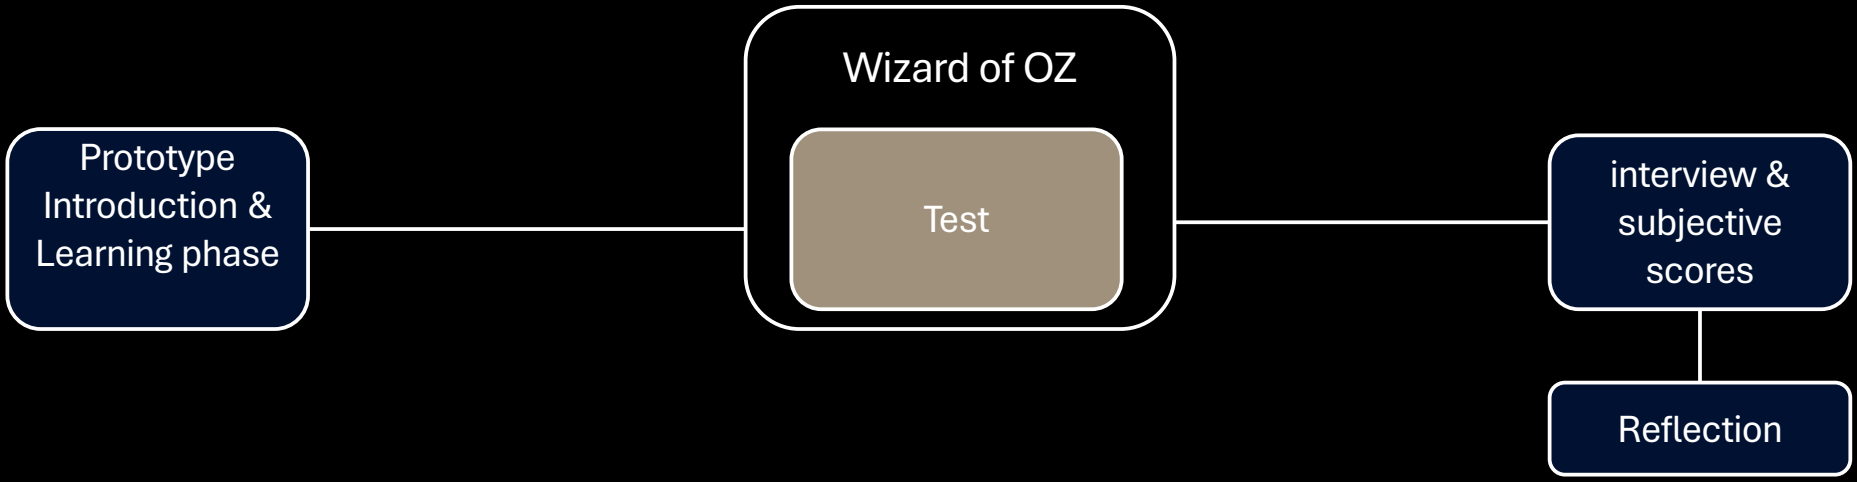
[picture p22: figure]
Prototype Introduction & Learning phase; interview & subjective scores; Reflection; Test; Wizard of OZ

See protocol develop 3

# Sample N=5

Name | Age | Relevance | Location | Time
Mario | 52 | Lost vision at age 30 | Licht en liefde | 07/05/2026
Jelle | 22 | Blind since birth | Licht en liefde | 07/05/2026
Herman | 65 | Lost vision at age 18 | Licht en liefde | 08/05/2026
Milo | 20 | Sighted (control) | At home | 08/05/2026
Milos | 20 | Sighted (control) | At home | 08/05/2026

# UX Feedback

"I still don't agree with the fact that you won't indicate which direction in your pulses.“

"Isn't that kind of the same thing?“

"It's really not that bad in terms of concentration."

"Rather indicating the direction where you already need to go."

- Patterns must remain consistent, even with multiple turns in quick succession
- Hesitated between announcement and obstacle pulse, patterns are too similar to each other
- The feedback logic of the compass (back to center = you are positioned correctly) was not immediately intuitive, but solvable through explanation
- Wants to be able to recognize the direction within the pattern itself
- Completely divergent feedback on turn announcements

# Vibe check

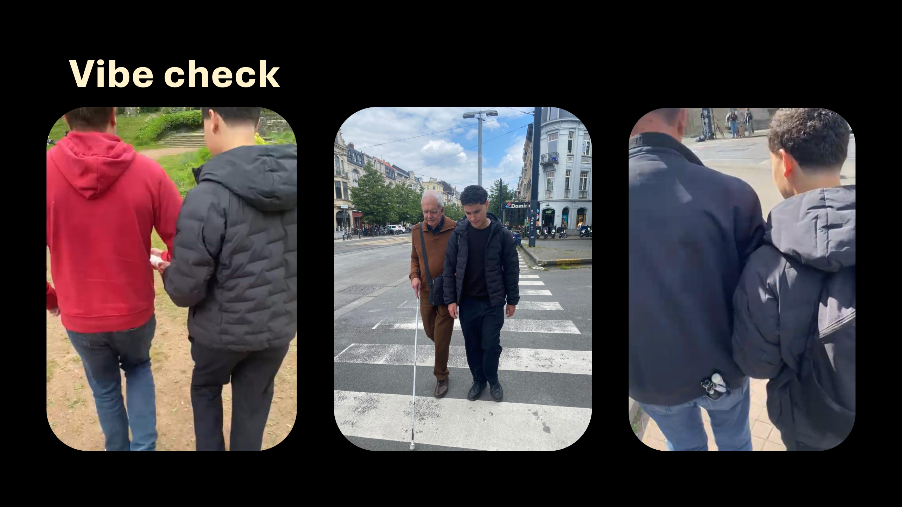
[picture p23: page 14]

# Design implicaties

- Groove width is good, but onboarding needs to be clear
- Differentiate more sharply between announcement vs. obstacle in length or rhythm
- Direction as a vibration pattern still as the default setting (adjustable afterwards)
- Silent default for walking, no announcement for micro-corrections is good and clear
- Announcement distance is very personal and must be adjustable
- Softer handle material as the primary choice
- Color itself is not important, but contrast is -> black or red handle
- The white cane itself is required to be white
- Replaceable compass pin is necessary

# CMF

# Handle

# Handle

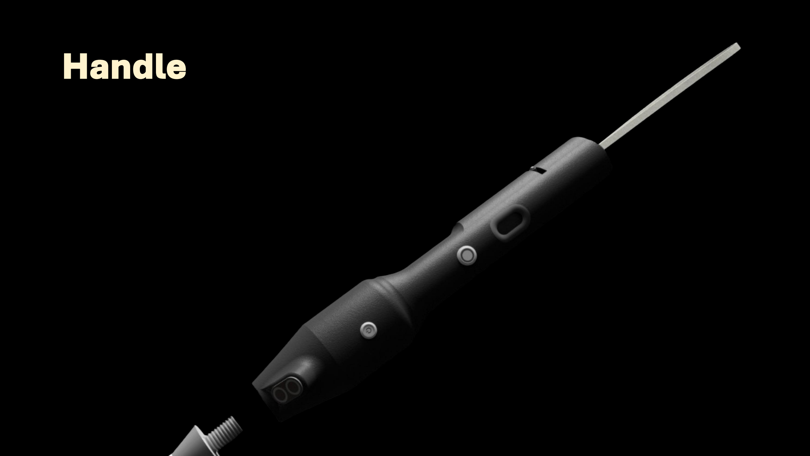
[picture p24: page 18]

# Handle

Component | Function | Why CMF-relevant
Structural core | Carries electronics (PCB, battery, LRA motor); provides threading for mounting | Lost vision at age 18
Soft-touch overmold | 55 | Severely visually impaired
Grip texture | Increases grip, helps user orient handle in hand | Pitch and depth of ribs/dots determine tactile legibility
Button | On/off, Smart-feature control | Must be tactilely distinct from other buttons via relief or contrast
Pin tip / pointer head | The end the user feels with the thumb to read direction | Most touched single point on the entire product — tactile shape and material are critical

# Structural core

Criterion (weight) | PA6-GF30 | PA6 unfilled | Polycarbonate (PC)
Rigidity / dimensional stability (×3) | 5 | 3 | 4
TPE overmold adhesion (×3) — Persson 2020 | 1 | 5 | 5
Weight (×2) | 4 | 4 | 3
UV resistance (×1) | 4 | 4 | 2
Production cost (×2) | 4 | 5 | 3
2K line availability BE/NL (×1) | 5 | 5 | 4
Total (max 60) | 40 | 49 | 44

# Structural core

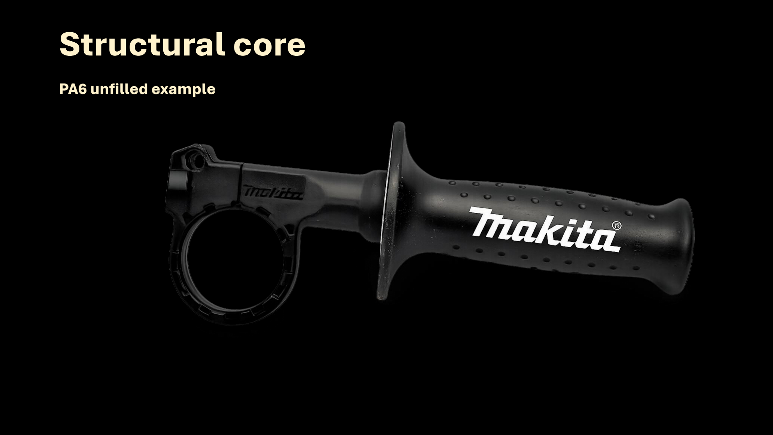
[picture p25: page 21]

PA6 unfilled example

# Soft-touch overmold (grip)

Criterion (weight) | TPE Shore 65A | TPU Shore 70A | Silicone Shore 70A
Tactile comfort over 8h use (×3) | 5 | 4 | 4
Grip in wet conditions (×3) | 4 | 5 | 4
2K overmold compatibility (×3) | 5 | 4 | 2
UV and colour fastness (×2) | 4 | 4 | 3
Recyclability (×1) | 4 | 3 | 1
Production cost (×2) | 5 | 3 | 2
Wear resistance (×1) | 3 | 5 | 4
Total (max 75) | 62 | 57 | 42

# Soft-touch overmold

TPE Shore 65A example


# Grip texture (mould-engraved pattern)

Criterion (weight) | Fine radial ribs (pitch 0.8 mm) | Diamond pattern (pitch 1.0 mm) | Linear ribs (pitch 1.2 mm)
Above tactile threshold for blind users (×3) — Alary 2008 | 5 | 5 | 5
Age-resilient legibility (×3) — Skedung 2018 | 5 | 5 | 5
Grip in wet conditions (×2) | 5 | 4 | 4
Cleanability / dirt traps (×2) | 4 | 2 | 4
Visual restraint (Quiet aesthetic) (×2) | 5 | 3 | 4
Mould engraving cost (VDI/Mold-Tech) (×1) | 4 | 3 | 5
Hand orientation cue (×1) | 5 | 3 | 4
Total (max 70) | 63 | 48 | 57

# Grip texture

Fine radial ribs (pitch 0.8 mm) example


# Buttons (cap material)

Criterion (weight) | POM (Delrin) + TPE 50A overlay | ABS + chrome ring | Silicone 60A solid
Click feel after 10,000 cycles (×3) | 5 | 4 | 3
Tactile distinction from grip (×3) — Norman 2011 | 5 | 3 | 4
Laser-engravable for icons (×2) | 4 | 5 | 2
IPX5 sealing compatibility (×2) | 5 | 4 | 5
Production cost (×1) | 3 | 5 | 4
Visual integration with grip (×2) | 5 | 3 | 4
Total (max 65) | 57 | 48 | 44

# Buttons


POM (Delrin) + TPE 50A overlay example

# Pin tip (compass indicator)

Criterion (weight) | TPE 50A on aluminium core | POM (Delrin) | Anodised aluminium 6061
Thermal comfort (cold morning, wet thumb) (×3) | 5 | 4 | 1
Tactile readability of direction notch (×3) | 5 | 4 | 5
Wear resistance (rotation, thumb friction) (×3) | 4 | 4 | 5
Premium feel (×2) | 5 | 2 | 5
Low-friction rotation (×2) | 4 | 5 | 4
Production cost (×1) | 3 | 5 | 3
Weight at the front of the handle (×1) | 4 | 5 | 3
Total (max 75) | 64 | 53 | 53

# Cane


# Cane

Component | Function | Why CMF-relevant
Shaft outer diameter | ~12 mm | WHO APS24
Shaft material | Aluminium, fibreglass, or graphite/carbon composite | WHO APS24, Wikipedia
Length | Based on user height (— typically 48–60 inch / 122–152 cm | Leader Dogs, BAWA
Tip material | Nylon or TPU | WHO APS24
Tip diameter | 2–3 cm | WHO APS24
Colour coding | White (upper) + red (lower) — legally required in most countries | National traffic laws
Expected lifespan | Min. 2 years under normal use | WHO APS24
Folding mechanism | Internal elastic cord (latex/polyester) running through all segments | WHO APS24

# Cane ISO 9999

# Develop 3 conclusions

Reassess; Prototypes; Test protocol; Research questions; User test

- Direction must be encoded in
the vibration pattern itself.

- Announcement and obstacle
pulses need sharper rhythmic
differentiation.

- Announcement distance:
customizable. Vibration
patterns: fixed defaults.

- Real-world cognitive load is
lower than lab predicted.

- Softer handle, high contrast,
white cane, replaceable pin.
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

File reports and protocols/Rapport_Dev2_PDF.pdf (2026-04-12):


# SensePath

Ear free, intuitive navigation in & outdoors


Prototypes

# Develop


# Methodology

# Develop 2

# Methodology


# Usability goals

### Effectiveness UG1 - Path accuracy: SIZ >= develop 1 on the benchmark path (observed) UG2 - Hesitation moments: <= number of hesitations in develop 1 (observed)

### Satisfaction UG3 - Cognitive load: Likert >= 4.5 (perceived) UG4 - Trust : Likert >= 5 (perceived) UG5 - Willingsness to use: Likert >= 5.5 (perceived)

### Preference ranking UG6 - Compass groove position: ranked preference across 5 positions (perceived) UG7 - Compass element: ranked preference across 5 elements (perceived)

# Anthropometrics

Method
- Hand model imported in Siemens NX via the ANSUR II database
- Design strategy: middle 50% of the population (P25–P75), male right hand, bare hands, finger-press posture
- Reference values: length 19.3 cm / breadth 8.8 cm (P50)

Designed dimensions
- Handle diameter calibrated to fit the middle 50% grip range
- Compass groove length sized so all 5 vertical positions fall within the active palm contact zone of the middle 50%
- Spacing between groove positions derived from finger-press contact mapping in NX

Validation
- Anthropometric output fed directly into the prototype CAD
- Validated empirically during user testing (Test 1 + Test 2) with Mario, Herman and Rory
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

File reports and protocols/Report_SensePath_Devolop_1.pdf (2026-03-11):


# SensePath

Ear free, intuitive navigation in & outdoors


Prototypes

# Develop


# Methodology

# Reassess

# Storyboard

Script: Claude Code · Image direction: Chat GPT · Generation: NanoBanana

# User-flow



# Matrix

# HPI


Prototypes

# Develop 1

# Methodology

Reasses; Prototypes; User test; Test protocol; Research; questions; New insights
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

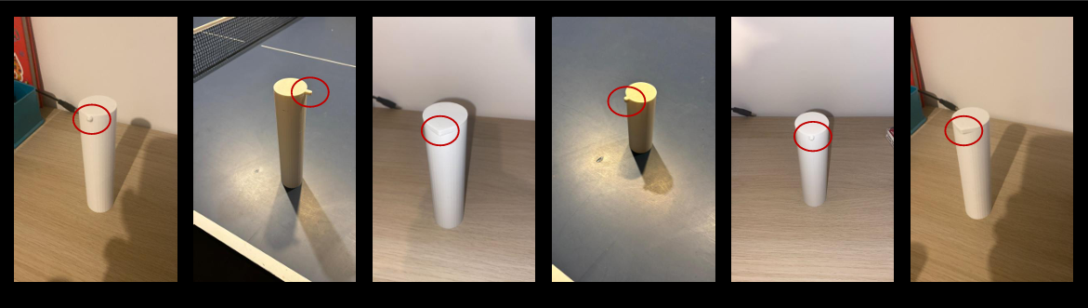
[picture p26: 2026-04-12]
img/contact_surface_prototype.png

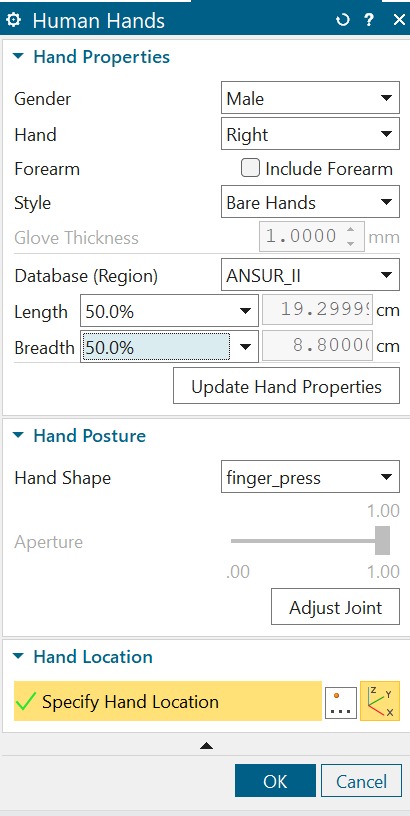
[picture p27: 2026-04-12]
img/NX_anthropometry_ANSUR_II.jpeg

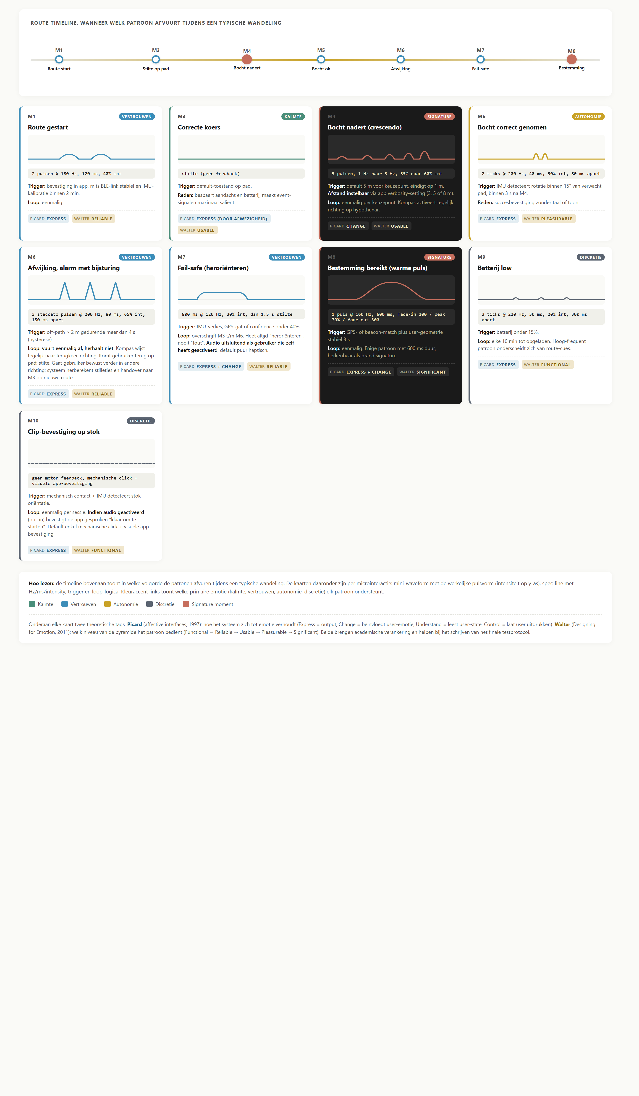
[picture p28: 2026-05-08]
docs/develop_3/microinteractions.png

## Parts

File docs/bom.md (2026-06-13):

# Bill of Materials (BOM)
## SensePath → MVP-prototype voor Deliver-validatie

> Documentatie van **ons MVP-prototype**, niet van het beoogde eindproduct. Voor het verschil tussen beide en de productie-vision (RTK GNSS, smartphone-app, ToF-obstakeldetectie, PA6 + TPE-materialen): zie de [Deliver-sectie in de hoofdrapportage](../README.md#deliver).

Deze BOM beschrijft de exacte componenten die voor het MVP-prototype zijn besteld en geïntegreerd. SensePath bestaat uit **drie fysieke modules**:

1. **Stok-onderstuk** ; conventionele lange witte stok met 3D-geprinte schroefdraad bovenaan en verwisselbare pin-tip onderaan. Geen elektronica.
2. **Tech-handvat** ; schroeft op het stok-onderstuk via een mee-geprinte schroefdraad. Bevat de XIAO ESP32-S3, DRV2605L + coin vibratiemotor, MG90S servo voor mechanisch kompas, opt-in MAX98357A + speaker, HOTUT drukknop (dubbele rol: functie + power-control via XIAO deep-sleep), eigen Li-Po + TP4056 USB-C. **Geen rocker-switch** ; physical-design constraint, power wordt softwarematig geregeld.
3. **Wizard-of-Oz controller** ; **fysiek aparte module** voor de testleider. Bevat een XIAO ESP32-C3, KY-040 roterende encoder, eigen Li-Po + TP4056 USB-C. **Draadloos** (ESP-NOW) verbonden met het tech-handvat ; geen kabel tussen testleider en gebruiker.

Modules 2 en 3 hebben elk hun eigen voeding en kunnen onafhankelijk aan- en uitgezet worden. Het tech-handvat is dagelijks omwisselbaar met een gewone handgreep via dezelfde 3D-geprinte schroefverbinding op het stok-onderstuk.

> Voor de bredere technische context: zie [wiring.md](wiring.md) voor het schakelschema en [build_guide.md](build_guide.md) voor de bouwinstructies.

---

# MODULE A → Tech-handvat (op de stok geschroefd)

Alle onderdelen in secties 1 tot en met 8 zitten in de **tech-handvat module** die de gebruiker in de hand heeft. Voor de Wizard-of-Oz controller-module zie sectie 9.

---

## 1. Besturingselektronica handvat

| Onderdeel | Specificatie | Aantal |
|---|---|---|
| Microcontroller | Seeed Studio XIAO ESP32-S3 (2.4 GHz WiFi + BLE 5.0, dual-core, met onboard Li-Po batterijlading) | 1 |
| Haptische driver | Adafruit DRV2605L Haptic Motor Controller [ADA2305] | 1 |

De XIAO ESP32-S3 is gekozen omwille van de compacte footprint (21 × 17.5 mm) en de ingebouwde Li-Po laad-ondersteuning ; minder externe componenten in het handvat. Hij ontvangt **draadloos via ESP-NOW** richting-updates van de controller-module en stuurt op basis daarvan de servo aan. De DRV2605L bevat een ROM met 123 haptische effecten en kan zowel ERM- als LRA-motoren aansturen.

---

## 2. Haptische actuator

| Onderdeel | Specificatie | Aantal |
|---|---|---|
| Coin vibratiemotor | DC 3 V, 80 mA, 11 000 RPM, 10 × 2.7 mm platte muntvorm (GERUI 1027-type) | 1 (uit pakket van 10) |

Een coin vibration motor is een ERM-type (Eccentric Rotating Mass) die door de DRV2605L wordt aangedreven in ERM-modus. De platte muntvorm laat een lage profielmontage toe tegen de binnenkant van het handvat, zonder dat de buitenmaten beïnvloed worden.

---

## 3. Mechanisch kompas

| Onderdeel | Specificatie | Aantal |
|---|---|---|
| Mini-servo | VUNIVERSUM MG90S, metalen tandwielen, 25 cm JR-kabel | 1 |

De MG90S stuurt het sferisch kompaselement aan. De assenpositie volgt de doelrichting die binnenkomt via de roterende encoder (Wizard-of-Oz) of, in een toekomstige autonome versie, via GPS-routing. Metalen tandwielen zijn gekozen voor langere levensduur onder herhaalde aansturing.

---

## 4. Wizard-of-Oz interface ; ontvangstkant

De KY-040 encoder zelf zit **niet** in het handvat ; die zit in een aparte controller-module (sectie 9). Het handvat ontvangt enkel de richtingsdata draadloos en stuurt daarmee de servo aan. Er is dus geen encoder-bedrading in het handvat zelf.

---

## 5. Audio (opt-in fallback)

| Onderdeel | Specificatie | Aantal |
|---|---|---|
| I2S audio-versterker | AZDelivery MAX98357A I2S Klasse D 3 W [ADA3006-compatible] | 1 |
| Speaker | Weewooday 2 W 8 Ω metalen behuizing, magneet, ronde mini-speaker | 1 (uit pakket van 6) |

Standaard staat de audio-output **uit**. Op gebruikersverzoek (zie Develop 3 → Jelle's suggestie) kan een spraak-fallback geactiveerd worden bij vastgelopen routes of onbekende situaties. Hierdoor blijft de "ear-free" positionering intact voor reguliere gebruikers, terwijl een opt-in noodvariant beschikbaar is.

---

## 6. Bedieningselementen handvat

| Onderdeel | Specificatie | Aantal |
|---|---|---|
| Drukknop | HOTUT IP67 waterdichte momentary drukknop, 12 mm hoge kop, metaal (variant: zwarte 32 mm momentary) | 1 (uit pakket van 6) |

Eén knop, drie functies via press-type onderscheid in firmware:
- **Short-press** (<500 ms) → start/stop route
- **Double-press** (binnen 400 ms) → "geef overzicht"
- **Long-press** (≥3 s) → XIAO gaat in deep-sleep (functioneel "uit")
- **Druk uit deep-sleep** → wake via EXT0 op RTC-GPIO 4

> **Geen rocker-switch op het handvat** ; physical-design constraint (geen plek in de huidige cap-geometrie). Power-control is volledig softwarematig via deep-sleep. Trade-off: het handvat trekt nog ~10 mA quiescent in deep-sleep (MT3608, MG90S idle, DRV2605L blijven onder spanning), wat neerkomt op ~4 dagen autonomie in opslag op een volle Li-Po. Voor langere opslag: USB-C aangesloten laten of de Li-Po-stekker fysiek loskoppelen van de TP4056.

---

## 7. Voeding handvat

| Onderdeel | Specificatie | Aantal |
|---|---|---|
| Li-Po accu | EEMB 3.7 V 1000 mAh met JST-PH connector | 1 |
| Laadcircuit | Aideepen TP4056 USB-C 5 V 1 A Li-Ion laadbord met overcharge en over-discharge protectie | 1 (uit pakket van 6) |
| Boost converter | MT3608 step-up DC-DC 2-24 V → 5-28 V verstelbaar (afgeregeld op 5 V voor audio-rail) | 1 (uit pakket van 3) |
| USB-C laad-poort | KUOQIY USB-C female 2-draads (VBUS + GND, alleen laden) | 1 (uit pakket van 6) |

De Li-Po levert 3.7 V direct aan de XIAO en (via de DRV2605L OUT-pinnen) de coin motor. De **MG90S servo** vraagt volgens datasheet 4.8-6 V om aan koppel-spec te draaien, en de **MAX98357A audio-versterker** heeft eveneens 5 V nodig. Daarvoor is de MT3608 boost ingezet die de 3.7 V opwaardeert naar een stabiele 5 V rail. De MT3608 staat **altijd aan** (servo moet altijd kunnen reageren op richting-updates); de audio-amp wordt apart in stand-by gezet via zijn SD-pin wanneer audio-fallback niet actief is, zodat de speaker geen stroom trekt. De externe USB-C female-breakout (2-draads) dient enkel voor opladen via TP4056; firmware-flashen gebeurt via de USB-C poort op de XIAO ESP32-S3 zelf.

---

## 8. Behuizing en grip handvat

| Onderdeel | Specificatie | Aantal | Toelichting |
|---|---|---|---|
| Handvat-core | 3D-print in PLA (productie-doel: PA6 unfilled) | 1 | Draagt de elektronica, het kompasmechanisme en de servo. PLA voor prototype-snelheid. |
| Overmold-grip | (productie-doel: TPE Shore 65A; in prototype niet aanwezig) | 0 | CMF-keuze gevalideerd in Develop 3, niet geïntegreerd in MVP-print. |
| Kompaselement | Sferisch contactoppervlak, laagste gleufpositie | 1 | Voorkeurconfiguratie uit Develop 2. |
| Mee-geprinte schroefdraad | 3D-geprint in PLA (geen los onderdeel) | 0 | In de bodem van het tech-handvat, voor de schroefverbinding met het stok-onderstuk. |

CMF-onderbouwing: zie Develop 3 in [README.md](../README.md).

---

# MODULE B → Wizard-of-Oz controller (fysiek apart, draadloos)

De controller is een **op zichzelf staande module** voor de testleider. Hij bevat zijn eigen microcontroller, encoder, batterij en oplaadcircuit. De data gaat draadloos via ESP-NOW naar het handvat ; er is geen kabel tussen beide modules.

## 9. Besturingselektronica controller

| Onderdeel | Specificatie | Aantal |
|---|---|---|
| Microcontroller | Seeed Studio XIAO ESP32-C3 (BLE 5.0 + WiFi, RISC-V, 21 × 17.5 mm, onboard Li-Po laad) | 1 |

De C3 is kleiner en zuiniger dan de S3 ; voor de controller hoeven we alleen encoder-deltas te verzenden, geen audio of servo aan te sturen. Dezelfde fysieke footprint en pinout-stijl als de S3, zodat dezelfde XIAO-ecosystem-bibliotheken hergebruikt kunnen worden.

## 10. Wizard-of-Oz input (controller)

| Onderdeel | Specificatie | Aantal |
|---|---|---|
| Roterende encoder | QWORK KY-040, 360° met geïntegreerde drukknop | 1 (uit pakket van 5) |

De testleider draait de KY-040 om de gewenste route-richting in te stellen. De ESP32-C3 leest CLK/DT/SW uit en verstuurt elke positie-update via ESP-NOW naar de ESP32-S3 in het handvat, die op zijn beurt de MG90S servo aanstuurt. De drukknop op de encoder dient als bevestiging of mode-wissel.

## 11. Voeding controller

| Onderdeel | Specificatie | Aantal |
|---|---|---|
| Li-Po accu | EEMB 3.7 V 1000 mAh met JST-PH connector | 1 |
| Laadcircuit | Aideepen TP4056 USB-C 5 V 1 A Li-Ion laadbord met overcharge en over-discharge protectie | 1 (uit pakket van 6) |
| USB-C laad-poort | KUOQIY USB-C female 2-draads (VBUS + GND, alleen laden) | 1 (uit pakket van 6) |

Identiek voedingsschema als het handvat (USB-C → TP4056 → Li-Po → 3.7 V rail) maar zonder MT3608 (geen 5 V rail nodig, geen audio).

## 12. Behuizing controller

| Onderdeel | Specificatie | Aantal | Toelichting |
|---|---|---|---|
| Controller-case | 3D-print in PLA, klein doosje (~60 × 40 × 25 mm) | 1 | Bevat ESP32-C3, batterij, TP4056, en heeft een opening bovenaan voor de KY-040 encoder-as. |

---

# MODULE C → Stok-onderstuk (passief, geen elektronica)

## 13. Stok-onderstuk

| Onderdeel | Specificatie | Aantal | Toelichting |
|---|---|---|---|
| Witte stok-onderstuk | Conventionele lange witte stok met verwisselbare pin-tip (productie-doel: aluminium of glasvezel; in prototype gemodificeerd standaardmodel) | 1 | Het onderstuk volgt de bestaande witte-stok-conventie. Wij integreren bovenaan een 3D-geprint draadstuk (vast op het uiteinde) waarop het tech-handvat geschroefd wordt. |
| 3D-geprint draadstuk | PLA, ~15 mm | 1 | Vast op het top-uiteinde van de stok. Schroeft in de mee-geprinte schroefdraad van het tech-handvat. |
| Verwisselbare pin-tip | Conventionele tip (rolling ball, ceramic, of glide tip) | 1 | Aan het loop-uiteinde, exact zoals bij commerciële witte stokken. |

---

# PROJECT-WIDE

## 14. Overige prototyping-materialen

| Onderdeel | Specificatie | Aantal |
|---|---|---|
| Dupont jumper wires | ZDE 10 cm, Female-Female, Male-Female, Male-Male, 120 stuks | Kit |
| Perfboard of mini-PCB | Voor DRV2605L ↔ XIAO bedrading (handvat) en ESP32-C3 ↔ encoder (controller) | 2 |
| Soldeer + flux | Sn60/Pb40 of loodvrij | naar wens |

---

## 15. Totale kost (indicatie, MVP-prototype als geheel)

**Module A → tech-handvat**

| Categorie | Richtprijs |
|---|---|
| XIAO ESP32-S3 + Adafruit DRV2605L | €25 → €35 |
| Coin vibration motor + speaker + MAX98357A | €10 → €15 |
| MG90S servo | €5 → €10 |
| HOTUT knop + USB-C laad-poort | €8 → €12 |
| TP4056 + MT3608 + Li-Po 1000 mAh | €10 → €15 |
| 3D-print (PLA, ~80 g) + hardware | €8 → €15 |
| **Subtotaal handvat** | **€66 → €102** |

**Module B → Wizard-of-Oz controller**

| Categorie | Richtprijs |
|---|---|
| XIAO ESP32-C3 | €8 → €12 |
| KY-040 encoder | €2 → €4 |
| TP4056 + Li-Po 1000 mAh | €8 → €12 |
| USB-C laad-poort | €2 → €4 |
| 3D-print case + hardware | €4 → €8 |
| **Subtotaal controller** | **€24 → €40** |

**Module C → Stok-onderstuk**

| Categorie | Richtprijs |
|---|---|
| Witte stok-onderstuk + 3D-geprint draadstuk | €15 → €30 |
| **Subtotaal stok** | **€15 → €30** |

| **Totaal MVP-prototype (alle drie modules)** | **€105 → €172** |

---

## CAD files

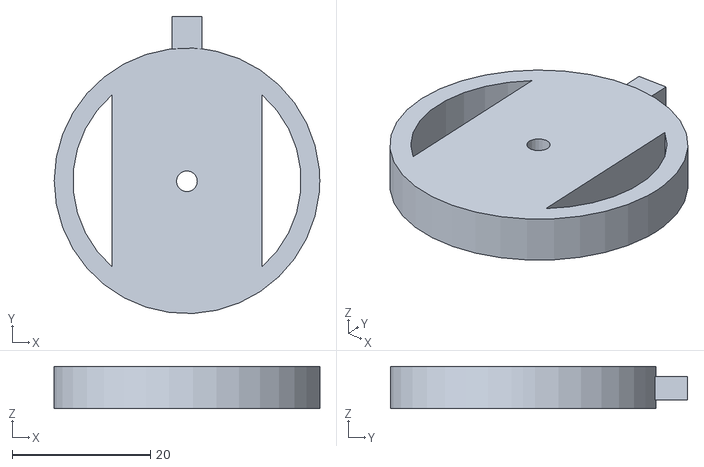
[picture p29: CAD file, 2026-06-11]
cad/exports/Kompas_3Dprint.stl
38.4 x 42.9 x 6.10

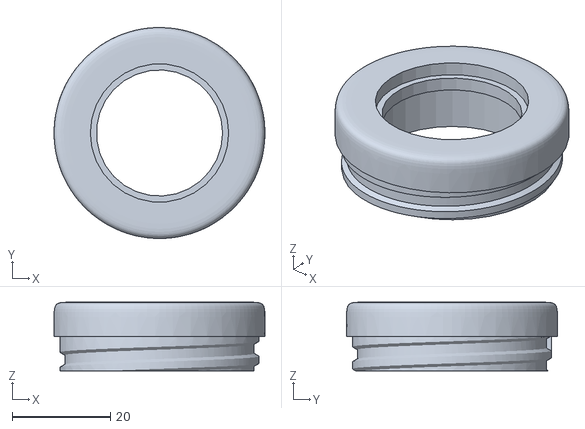
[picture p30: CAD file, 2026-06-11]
cad/exports/boxhold_3Dprint.stl
43.0 x 43.0 x 14.0

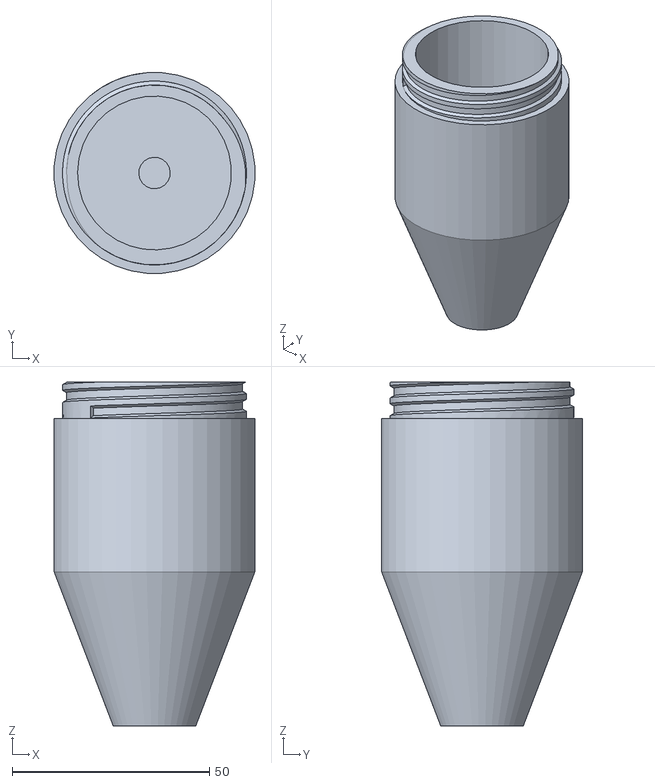
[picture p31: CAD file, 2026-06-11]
cad/exports/opzetstukbehuizing_3Dprint.stl
50.8 x 50.8 x 87.2

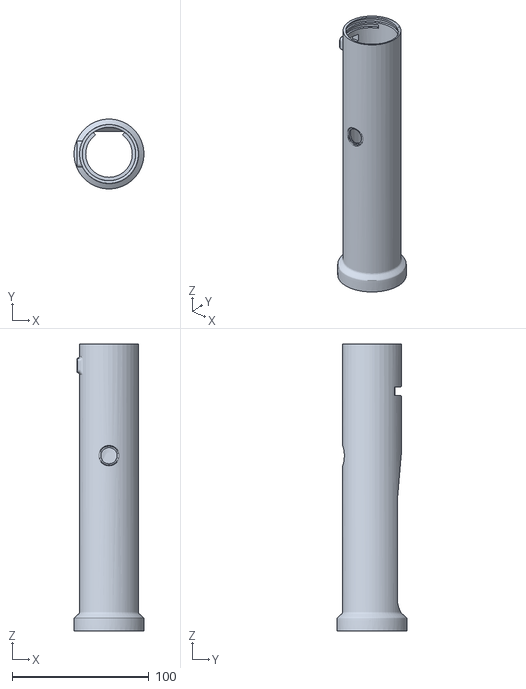
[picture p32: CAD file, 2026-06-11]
cad/exports/behuizingstok_3Dprint.stl
51.0 x 51.0 x 209.5

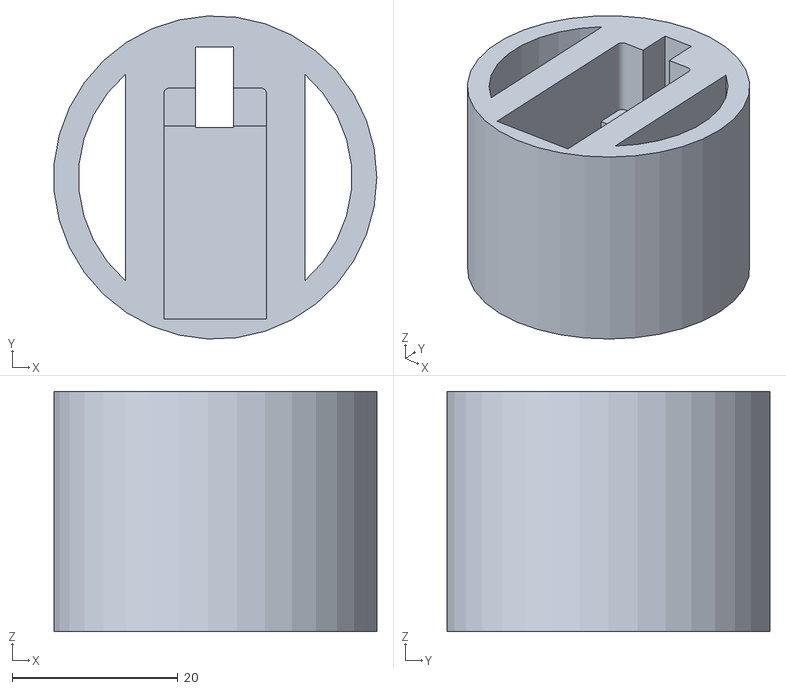
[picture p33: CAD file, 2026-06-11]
cad/exports/servobehuizing_3Dprint.stl
38.9 x 39.0 x 29.0

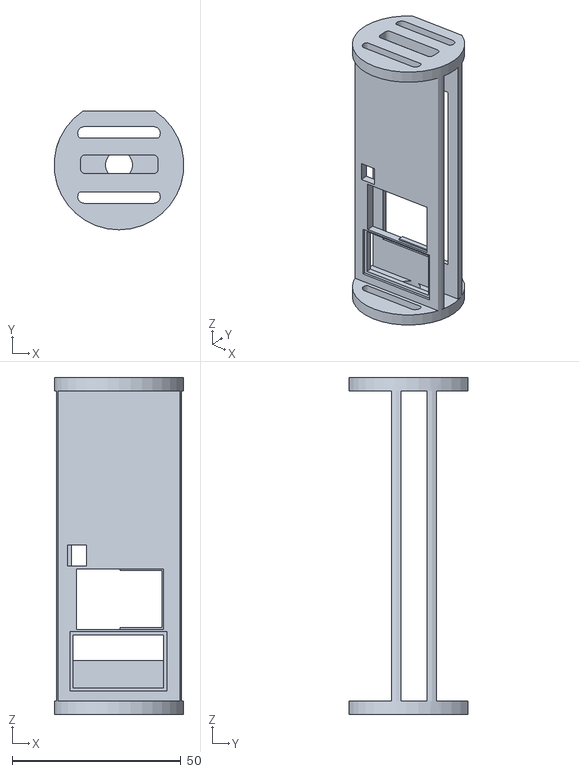
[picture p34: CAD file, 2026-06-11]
cad/exports/elektronica_3Dprint.stl
38.4 x 35.2 x 100.0

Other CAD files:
cad/protoype_handvat_trillingmotoren.prt
cad/quick&dirty_trillingshandvat.prt

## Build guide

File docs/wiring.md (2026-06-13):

# Schakelschema → SensePath MVP-prototype

> Documentatie van **ons MVP-prototype**, niet van het beoogde eindproduct. De productie-vorm zou onder andere RTK GNSS-ontvangst, BLE-app-koppeling en ToF-obstakeldetectie toevoegen ; zie de [Deliver-sectie in de hoofdrapportage](../README.md#deliver) voor de vertaalstap.

Dit document beschrijft hoe de elektronica in het MVP-prototype onderling verbonden is. Het is bedoeld om een externe bouwer toe te laten het systeem te reproduceren zonder reverse-engineering. Zie [bom.md](bom.md) voor de stuklijst en [build_guide.md](build_guide.md) voor de bouwvolgorde.

---

## Architectuur ; drie fysieke modules

Het systeem bestaat uit **drie fysieke onderdelen** die elk een afzonderlijke rol hebben:

1. **Stok-onderstuk** (passief) → conventionele witte stok met 3D-geprinte schroefdraad bovenaan en verwisselbare pin-tip onderaan. Geen elektronica.
2. **Tech-handvat** (eindgebruiker) → bevat de XIAO ESP32-S3, DRV2605L + coin vibratiemotor, MG90S servo voor mechanisch kompas, opt-in audio (MAX98357A + speaker), HOTUT drukknop (dubbele rol: functie + power-control via deep-sleep), Li-Po batterij + TP4056 USB-C oplaad, MT3608 boost voor 5V rail. Schroeft op het stok-onderstuk.
3. **Wizard-of-Oz controller** (testleider) → een **fysiek aparte module** met een **XIAO ESP32-C3**, een KY-040 roterende encoder en eigen Li-Po batterij + TP4056 USB-C oplaad. **Draadloos** (ESP-NOW peer-to-peer) verbonden met het tech-handvat.

```mermaid
flowchart LR
    subgraph CTRL["Controller-module → testleider"]
        ENC[KY-040 encoder<br/>+ drukknop]
        C3[XIAO ESP32-C3]
        BAT2[Li-Po 1000 mAh]
        TP2[TP4056 USB-C]
        USBC2[USB-C laad-poort]
        USBC2 --> TP2
        TP2 <--> BAT2
        BAT2 --> C3
        ENC -->|CLK / DT / SW| C3
    end

    subgraph HANDLE["Tech-handvat → eindgebruiker"]
        S3[XIAO ESP32-S3<br/>deep-sleep capable]
        SERVO[MG90S servo<br/>kompas-aansturing]
        DRV[DRV2605L]
        COIN[Coin vibratiemotor]
        AMP[MAX98357A]
        SPK[Speaker]
        BTN[HOTUT drukknop<br/>functie + wake/sleep]
        BAT1[Li-Po 1000 mAh]
        TP1[TP4056 USB-C]
        BOOST[MT3608 boost]
        USBC1[USB-C laad-poort]
        USBC1 --> TP1
        TP1 <--> BAT1
        BAT1 --> S3
        BAT1 --> BOOST
        BOOST --> SERVO
        BOOST --> AMP
        S3 <-->|I2C| DRV --> COIN
        S3 -->|PWM| SERVO
        S3 -->|I2S + SD-gate| AMP --> SPK
        BTN -->|D3 wake/short/long| S3
    end

    C3 -.->|ESP-NOW draadloos<br/>2.4 GHz| S3
```

De keten **testleider → KY-040 → ESP32-C3 → ESP-NOW → ESP32-S3 → servo → mechanisch kompas → blinde gebruiker** is de Wizard-of-Oz bridge tussen het Develop 3 prototype en een toekomstig autonoom GPS-systeem. Voor de gebruiker maakt het niet uit wie de signalen genereert; voor de testleider werkt het exact zoals een gewone fysieke knop.

> **Communicatieprotocol** ; ESP-NOW is de default (peer-to-peer WiFi, ~2 ms latency, geen router nodig). BLE 5.0 is een gelijkwaardig alternatief; beide chips ondersteunen het.

---

## Module 1 → tech-handvat (XIAO ESP32-S3)

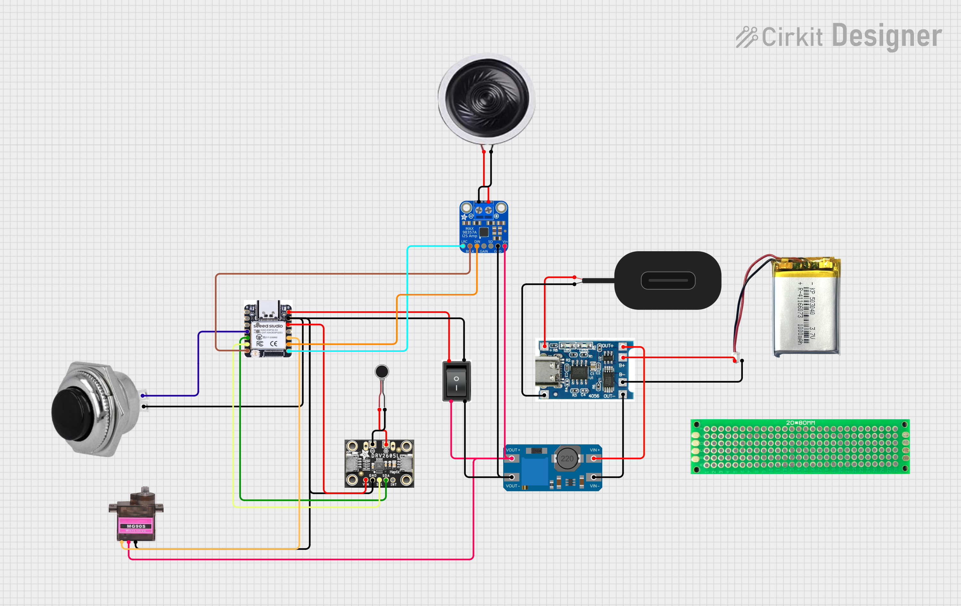
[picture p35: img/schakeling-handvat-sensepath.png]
Schakeling van het tech-handvat met XIAO ESP32-S3 als centrale microcontroller, omringd door alle peripherals en het voedingscircuit


*Schakelschema van het tech-handvat (Cirkit Designer). Centraal staat de **XIAO ESP32-S3** met USB-C-poort bovenaan. Linksboven de **HOTUT drukknop** naar D3. Onderaan de **MG90S servo** voor het mechanisch kompas, daarboven de **DRV2605L** breakout die de coin vibratiemotor aandrijft via I2C. Bovenaan de I2S audio-keten met **MAX98357A** versterker en speaker (opt-in fallback). Rechts het voedingstraject: **USB-C laadpoort** → **TP4056** → **Li-Po 1000 mAh** → enerzijds direct naar de XIAO 5V-pad, anderzijds via de **MT3608 boost** naar de 5 V rail voor servo en audio-amp. Het groene perfboard (20×80 mm) onderin is de fysieke draagplaat voor handmatige soldeerverbindingen.*

> **Opmerking** ; deze visualisatie toont een tussen-iteratie waarin nog een aparte rocker-switch zat (de zwarte kantelschakelaar in het midden). In de finale uitvoering (zie de tabel hieronder + de paragraaf [Voeding](#voeding)) is die rocker vervangen door power-control via de HOTUT-drukknop in combinatie met deep-sleep, wat één component en één behuizings-uitsparing uitspaart.

### Pinout-tabel

| Functie | XIAO ESP32-S3 pin | Naar | Opmerking |
|---|---|---|---|
| 5V in | 5V-pad onderzijde | TP4056 OUT+ direct (geen rocker meer) | Continu gevoed; XIAO regelt aan/uit via deep-sleep |
| 3V3 uit | 3V3 | DRV2605L Vin | Voor 3.3 V logic peripherals |
| GND | GND | Gemeenschappelijke massa | Alle modules delen één GND-bus binnen het handvat |
| I2C SDA | D4 (GPIO 5) | DRV2605L SDA | I2C-pull-ups geïntegreerd op breakout |
| I2C SCL | D5 (GPIO 6) | DRV2605L SCL | Idem |
| Drukknop / wake | D3 (GPIO 4, RTC-GPIO) | HOTUT knop signaal | Interne pull-up, sluit naar GND. Korte druk = functie; lange druk = deep-sleep; druk uit deep-sleep = wake (EXT0 low-level wake) |
| Servo PWM | D9 (GPIO 8) | MG90S signaal-pin (oranje) | 50 Hz PWM, 1-2 ms duty. 3.3 V logic-level volstaat (MG90S triggert al boven ~2.5 V) |
| I2S BCLK | D6 (GPIO 43) | MAX98357A BCLK | Bit clock voor audio |
| I2S LRC | D7 (GPIO 44) | MAX98357A LRC | Left-right clock |
| I2S DIN | D8 (GPIO 7) | MAX98357A DIN | Data input |
| Audio amp SD | D10 (GPIO 9) | MAX98357A SD | Software-gated power gate. LOW = shutdown (~0 mA), HIGH = mono-mix actief. 100 kΩ pull-down naar GND voor gedefinieerde boot-state |
| Servo + | 5V rail (uit MT3608) | MG90S V+ (rood) | Datasheet specificeert 4.8-6V; deelt rail met audio-amp |
| Audio amp + | 5V rail (uit MT3608) | MAX98357A Vin | Zelfde rail als servo; SD-pin gates het audio-pad |
| Audio amp GAIN | GND | MAX98357A GAIN | Direct naar GND = 15 dB max gain (kleine speaker, spraak-fallback in handvat) |
| Coin motor + | DRV2605L OUT+ | Coin vibratiemotor terminal 1 | Door DRV2605L gegenereerde ERM-drive (geen rechtstreekse XIAO-pin) |
| Coin motor − | DRV2605L OUT− | Coin vibratiemotor terminal 2 | Polariteit niet kritisch voor ERM-coin motor |

### Voeding

```mermaid
flowchart LR
    USBC1[USB-C laad-poort] --> TP1[TP4056]
    TP1 <--> BAT1[Li-Po 3.7V 1000mAh]
    BAT1 --> RAIL37[3.7V rail<br/>continu gevoed]
    RAIL37 --> XIAOPWR[XIAO ESP32-S3<br/>deep-sleep capable]
    RAIL37 --> BOOST[MT3608 boost<br/>altijd aan]
    BOOST --> RAIL5[5V rail]
    RAIL5 --> SERVO[MG90S servo<br/>+ 220-470µF elco]
    RAIL5 --> AMP[MAX98357A<br/>SD-pin gates audio]
    XIAOPWR -->|3V3| DRV[DRV2605L Vin]
    DRV -->|OUT± drive| COIN[Coin vibratiemotor]
    HOTUT[HOTUT knop] -->|D3 / EXT0 wake| XIAOPWR
```

Drie rails binnen het handvat: één **3.7 V rail** rechtstreeks van de Li-Po die de XIAO voedt; één **5 V rail** uit de MT3608 boost converter die zowel de MG90S servo als de MAX98357A audio-amp voedt; en het **USB-C laadkanaal** via de TP4056. De MT3608 staat **altijd aan** (de servo heeft volgens datasheet 4.8-6 V nodig om aan spec te draaien); de audio-amp wordt apart in stand-by gezet via zijn SD-pin wanneer audio-fallback niet actief is, zodat de speaker geen stroom trekt.

> **Geen aparte rocker-switch**. De HOTUT-drukknop vervult een dubbele rol: korte druk = functie (start/stop, overzicht), **lange druk (~3 s) = XIAO gaat in deep-sleep**, druk uit deep-sleep = wake via EXT0. In "uit"-stand (deep-sleep) blijft de MT3608, MG90S en DRV2605L wel onder spanning ; totaal ~10 mA quiescent draw. Op 1000 mAh = ~4 dagen voor het handvat zichzelf leeg trekt. Voor langere opslag: USB-C aangesloten laten of de Li-Po-stekker fysiek loskoppelen.

### Peripherals binnen het handvat

**HOTUT drukknop (dubbele rol → functie + power-control)** ; momentane drukknop, één pool naar XIAO D3 (RTC-GPIO 4), één pool naar GND. Interne pull-up actief; software detecteert verschillende press-types met 20 ms debounce:

| Press-type | Detectie | Actie |
|---|---|---|
| Korte druk (<500 ms) | Pulse op D3 | Functie: start/stop route |
| Dubbel-druk (binnen 400 ms) | Twee pulses op D3 | Functie: "geef overzicht" |
| Lange druk (≥3 s) | D3 LOW gedurende 3 s | XIAO sluit MAX98357A SD af, zet alle outputs neutraal, roept `esp_deep_sleep_start()` aan |
| Druk uit deep-sleep | EXT0 wake-up trigger | XIAO boot opnieuw, hervat normale werking |

> Geen rocker-switch in deze configuratie. De HOTUT is de enige user-facing power-control; de Li-Po blijft fysiek aangesloten.

**DRV2605L → coin vibratiemotor** ; ERM-modus, I2C-adres 0x5A, motor hangt aan OUT+/OUT-.

**MG90S servo → mechanisch kompas** ; PWM-signaal op D9 (3.3 V logic werkt direct, geen level shifter nodig). V+ op de 5 V rail uit de MT3608 boost, GND op de gemeenschappelijke massa. **Belangrijk**: plaats een **220-470 µF elco** tussen V+ en GND vlak bij de servo-stekker. De MG90S kan tot ~300 mA pieken trekken bij snelle beweging ; zonder buffercap zakt de 5 V rail kortstondig in en kan de XIAO resetten. Klassieke valkuil bij servo + microcontroller op één Li-Po. De servo ontvangt zijn doelhoek van de XIAO, die op zijn beurt het signaal krijgt **van de controller-module via ESP-NOW**, niet van een lokaal aangesloten encoder.

**MAX98357A + speaker** ; I2S audio (opt-in fallback). De SD-pin op de MAX98357A is **geen simpele on/off**: hij is een 4-staats input die zowel shutdown als kanaal-selectie regelt. Onze configuratie:

| SD-spanning | Effect | Hoe wij hem aansturen |
|---|---|---|
| 0 → 0.16 V | Shutdown (~0 mA) | XIAO D10 LOW = default |
| 0.16 → 0.77 V | Stereo-mix (L+R)/2 | XIAO D10 HIGH (3.3 V) **valt buiten dit bereik**, zie noot |
| 0.77 → 1.4 V | Right channel | n.v.t. |
| 1.4 V → Vdd | Left channel | XIAO D10 HIGH valt hierin → wij krijgen left channel |

Daarom: **D10 LOW = amp uit; D10 HIGH = amp aan in left-channel mode** (bij ons functioneel identiek aan mono omdat de speaker een mono-bron is). De **100 kΩ pull-down** tussen SD en GND houdt de pin LOW tijdens boot en reset (XIAO GPIOs zijn floating high-impedance tot `pinMode` aanroep). De **GAIN-pin** is direct aan GND voor 15 dB versterking.

Software in firmware:
```cpp
const uint8_t AUDIO_SD_PIN = 10;  // XIAO D10
pinMode(AUDIO_SD_PIN, OUTPUT);
digitalWrite(AUDIO_SD_PIN, LOW);   // default: amp in shutdown
// Bij audio-fallback activatie:
digitalWrite(AUDIO_SD_PIN, HIGH);  // amp wakker, klaar om I2S te spelen
```

---

## Module 2 → Wizard-of-Oz controller (XIAO ESP32-C3)

De controller is een **fysiek aparte module** die de testleider in de hand houdt of aan de gordel draagt. Hij stuurt via draadloos signaal de servo in het handvat aan ; voor de gebruiker is het verschil tussen "wizard met fysieke knop" en "autonoom GPS-systeem" niet voelbaar.

### Componenten in deze module

- 1× Seeed XIAO ESP32-C3 (kleinere variant van de S3, dezelfde formfactor en pinning maar met BLE 5.0 + WiFi, geen camera-interface ; voldoende voor encoder-uitlezen en draadloze verzending)
- 1× KY-040 roterende encoder met geïntegreerde drukknop
- 1× Li-Po 3.7 V 1000 mAh
- 1× TP4056 USB-C laadcircuit
- 1× USB-C female laad-poort

### Pinout-tabel

| Functie | XIAO ESP32-C3 pin | Naar | Opmerking |
|---|---|---|---|
| 5V in | 5V-pad | TP4056 OUT+ direct | Continu gevoed; aan/uit via firmware-deep-sleep of fysiek loskoppelen Li-Po |
| 3V3 uit | 3V3 | KY-040 + (Vcc) | Voor encoder logic |
| GND | GND | Encoder GND, batterij GND, TP4056 GND | Gemeenschappelijke massa binnen de controller |
| Encoder CLK | D0 (GPIO 2) | KY-040 CLK (A) | Interrupt-capable input |
| Encoder DT | D1 (GPIO 3) | KY-040 DT (B) | Tweede kanaal voor rotatierichting |
| Encoder SW | D2 (GPIO 4) | KY-040 SW (drukknop) | Push-bevestiging, interne pull-up |

> Pin-mapping op de ESP32-C3 verschilt licht van de S3 (kleinere GPIO-range). De `Dx`-labels op het XIAO-board komen overeen met andere onderliggende GPIO-nummers. Werk altijd met de fysieke `Dx`-aanduiding.

### Voeding (identiek principe als het handvat, simpeler omdat geen servo of audio)

```mermaid
flowchart LR
    USBC2[USB-C laad-poort] --> TP2[TP4056]
    TP2 <--> BAT2[Li-Po 3.7V 1000mAh]
    BAT2 --> C3[XIAO ESP32-C3]
    C3 --> ENC[KY-040 encoder]
```

Eén enkele 3.7 V rail volstaat ; geen boost converter, geen audio. Verbruik laag (~30 mA gemiddeld) → autonomie ruim 24 uur op 1000 mAh.

---

## Draadloze link tussen modules

**Default: ESP-NOW** (peer-to-peer protocol op de 2.4 GHz WiFi-radio):

| Eigenschap | Waarde |
|---|---|
| Latency | ~2 ms typisch, <5 ms piek |
| Bereik | 50 → 100 m line-of-sight, ~10 m door muren |
| Bandbreedte | ruim voldoende voor encoder-deltas (enkele bytes per update) |
| Pairing | MAC-adres van de S3 in C3-firmware hardcoded; geen WiFi-AP nodig |
| Encryptie | optioneel via AES-128 |

**Alternatief: BLE 5.0** ; iets hogere latency maar geschikt voor de toekomst wanneer ook een smartphone-app meekoppelt op het handvat.

### Verzonden data-formaat (ontwerp)

De controller verstuurt periodiek (~50 Hz) een kort pakket:

```
struct EncoderUpdate {
    int16_t  delta;     // rotatie sinds vorige update
    int16_t  absolute;  // absolute encoder-positie (0-360°)
    uint8_t  buttons;   // bitfield: bit 0 = SW ingedrukt
    uint8_t  sequence;  // wraparound counter
}
```

In het handvat vertaalt de S3-firmware de `absolute` waarde naar een servo-hoek (0-180°) met een lineaire mapping. De `delta` is voor responsiviteit; `buttons` triggert eventueel een mode-wissel.

---

## I2C-bus (binnen het handvat)

| Eigenschap | Waarde |
|---|---|
| Bus-spanning | 3.3 V |
| Snelheid | 100 kHz standaard (Wire library default) |
| Adres DRV2605L | 0x5A (factory default) |
| Pull-up weerstanden | 4.7 kΩ → geïntegreerd op Adafruit-breakout |

Geen multiplexing nodig: DRV2605L is het enige I2C-device op de bus.

---

## I2S audio-bus (opt-in, binnen het handvat)

| Signaal | Functie |
|---|---|
| BCLK | Bit clock, gegenereerd door XIAO ESP32-S3 (D6) |
| LRC (WS) | Word select / Left-Right clock (D7) |
| DIN | Data input naar amplifier (D8) |
| SD | Power gate, aangestuurd door XIAO D10 + 100 kΩ pull-down |
| GAIN | Direct aan GND voor 15 dB versterking |
| GND | Gemeenschappelijke massa |
| Vin (5V) | Via MT3608 boost (zelfde rail als servo) |

De MAX98357A heeft geen master-volume input; volume wordt softwarematig geregeld op de XIAO. Stand-by gebeurt via de SD-pin (XIAO D10 LOW) ; default-stand om de ~50 mA idle-draw van de versterker te vermijden zolang audio-fallback niet actief is. Op een 1000 mAh Li-Po geeft dat ongeveer een verdubbeling van de actief-autonomie ten opzichte van een altijd-aan amp.

---

## PWM-signaal voor servo (binnen het handvat)

| Eigenschap | Waarde |
|---|---|
| Frequentie | 50 Hz (standaard servo-protocol) |
| Pulsduur 0° | ~1 ms |
| Pulsduur 90° | ~1.5 ms |
| Pulsduur 180° | ~2 ms |
| Mapping in code | controller-encoder absolute (0-360°) → servo-hoek (0-180°) via lineaire mapping |

De MG90S verbruikt ~150-300 mA tijdens snelle beweging; in stilstand 5-10 mA.

---

## Power budget

### Handvat-module

| Component | Idle (sessie) | Actief | Piek | Deep-sleep ("uit") |
|---|---|---|---|---|
| XIAO ESP32-S3 (ESP-NOW actief) | ~30 mA | ~50 mA | 240 mA tijdens transmit | ~14 µA (deep-sleep, EXT0 wake armed) |
| DRV2605L | ~2 mA | ~6 mA | → | ~2 mA (Vin nog gevoed via XIAO 3V3 LDO) |
| Coin vibration motor | 0 mA | ~80 mA (continu) | ~120 mA piek | 0 mA |
| MG90S servo (op 5 V uit MT3608) | ~5 mA | ~150 mA (bewegend) | ~300 mA piek | ~5 mA (idle, geen shutdown-pin) |
| MT3608 boost (altijd aan, quiescent) | ~1 mA | ~3 mA (met servo-load) | → | ~1 mA quiescent |
| MAX98357A + speaker (audio uit, SD low) | ~0 mA | → | → | ~0 mA |
| MAX98357A + speaker (audio aan) | ~50 mA | ~250 mA | ~500 mA piek | n.v.t. (SD low in deep-sleep) |
| HOTUT knop | 0 mA (passief) | → | → | 0 mA |
| **Totaal handvat (audio uit, in sessie)** | **~40 mA** | **~250 mA** | **~550 mA piek** | **~10 mA in deep-sleep** |

**Autonomie-impact**:
- In sessie (idle): ~25 u theoretisch / ~5-7 u realistisch met regelmatige servo-beweging
- In "uit"-stand (deep-sleep): ~100 u = ~4 dagen op volle 1000 mAh Li-Po
- Conclusie: **na elke testdag opladen via USB-C**, of de USB-C aangesloten laten tijdens opslag tussen sessies. Voor weken-langdurige opslag de Li-Po-stekker fysiek loskoppelen.

Handvat op 1000 mAh Li-Po → ~9 uur theoretisch, ~5 → 7 uur realistisch met regelmatige servo-beweging.

### Controller-module

| Component | Idle | Actief | Piek |
|---|---|---|---|
| XIAO ESP32-C3 (ESP-NOW actief) | ~20 mA | ~30 mA | ~80 mA tijdens transmit |
| KY-040 encoder | 0 mA (passief) | → | → |
| **Totaal** | **~20 mA** | **~30 mA** | **~80 mA piek** |

Controller op 1000 mAh Li-Po → ruim 30+ uur autonomie, in praktijk een hele test-dag op één lading.

---

## Visualisatie

Een volledig geannoteerd visueel schema (met beide modules en de RF-link) staat in [../Project context/sensepath_wiring_schematic.html](../Project%20context/sensepath_wiring_schematic.html). Open in browser.

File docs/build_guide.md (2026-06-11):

# Build guide → SensePath MVP-prototype

> Bouwinstructies voor **ons MVP-prototype**, niet voor het beoogde eindproduct. Zie de [Deliver-sectie in de hoofdrapportage](../README.md#deliver) voor wat in een productie-versie nog toegevoegd zou worden (RTK GNSS-ontvangst, BLE-app, ToF-obstakeldetectie, PA6 + TPE-materialen).

Stap-voor-stap instructies om het SensePath MVP zelf te bouwen. Het systeem bestaat uit **drie modules** die elk afzonderlijk gebouwd worden:

- **Module A → Tech-handvat** (XIAO ESP32-S3 + servo + motor + audio + HOTUT-knop met dubbele rol + batterij; geen rocker-switch, power via deep-sleep) → secties 1 tot 5
- **Module B → Wizard-of-Oz controller** (XIAO ESP32-C3 + KY-040 encoder + eigen batterij) → sectie 6
- **Module C → Stok-onderstuk** (conventionele witte stok met 3D-geprint draadstuk) → sectie 1.5 (samen met de print-stappen)

Lees eerst [bom.md](bom.md) voor de onderdelen en [wiring.md](wiring.md) voor het schakelschema. Geschatte bouwtijd: 6 → 10 uur (exclusief 3D-print). De controller-module voegt ongeveer 1.5 uur toe op de handvat-bouwtijd.

> Dit is een **werkversie**: voldoende om de bouwvolgorde te volgen, maar enkele detail-keuzes (firmware-pinout, ESP-NOW pairing, audio-volume defaults) worden tijdens de eindintegratie nog gefinetuned.

---

## Sectie 1 → 3D-print

<p align="center">
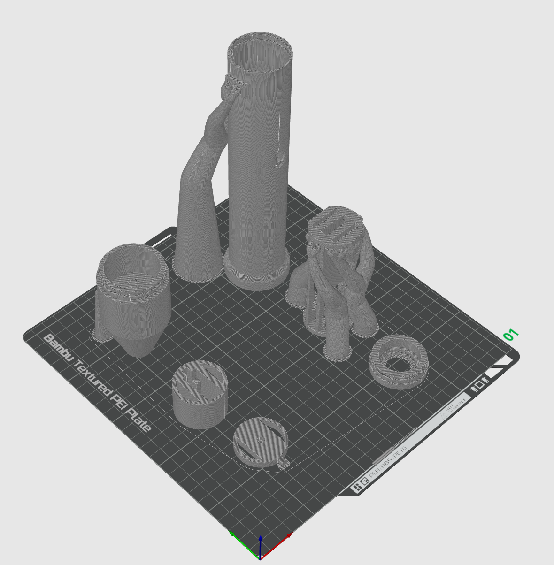
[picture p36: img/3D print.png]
3D-geprinte onderdelen van het SensePath-handvat
  
  <br/><em>De 3D-geprinte onderdelen van het tech-handvat en de modules.</em>
</p>

### Bestanden

Open [cad/exports/](../cad/exports/) en download de STL-bestanden:
- `behuizingstok_3Dprint.stl` ; hoofdbehuizing van het tech-handvat (stok-zijde)
- `opzetstukbehuizing_3Dprint.stl` ; opzetstuk-behuizing bovenaan het handvat
- `servobehuizing_3Dprint.stl` ; behuizing voor de MG90S servo (kompas-aandrijving)
- `Kompas_3Dprint.stl` ; sferisch kompaselement, koppelt op de servo-as
- `elektronica_3Dprint.stl` ; houder/frame voor de elektronica in het handvat
- `boxhold_3Dprint.stl` ; behuizing van de Wizard-of-Oz controller-module

> De NX-bronbestanden staan in [cad/](../cad/); van daaruit kun je desgewenst zelf opnieuw exporteren (export → faceted body).

### Aanbevolen print-instellingen

| Parameter | Waarde | Opmerking |
|---|---|---|
| Laagdikte | 0.16 mm | Balans tussen detail en tijd |
| Infill | 40 % gyroid | Stevigheid handvat zonder gewichtspenalty |
| Wandlagen | 4 | Voor slijtvastheid grip-zone |
| Print-oriëntatie | Handvat verticaal, gleuf naar boven | Minimale supports |
| Supports | Tree, alleen overhangen >50° | Trees breken makkelijk vrij |
| Materiaal core | PA6 unfilled | Slag- en slijtvast |
| Materiaal cap | PETG (alt: PLA) | Vlotter te printen, minder belast |

### Post-processing

1. Supports verwijderen en gleuf-rand met fijn schuurpapier (P800) gladstrijken.
2. De schroefdraad onderaan het tech-handvat wordt **mee-geprint** (geen heatset-insert) ; controleer de draadgang en strijk indien nodig glad met een M-tap of fijn schuurpapier. Dit is de schroefverbinding met het stok-onderstuk.
3. Sferisch kompaselement op de servo-as schuiven (kruisbout meegeleverd met MG90S) en testen op vrije rotatie binnen de gleuf.

### Stok-onderstuk voorbereiden

1. Conventionele lange witte stok nemen (aluminium of glasvezel) ; we behouden de bestaande pin-tip aan het loop-uiteinde, exact zoals bij commerciële witte stokken.
2. Standaard handgreep van de stok verwijderen (meestal vastgelijmd of geklemd).
3. 3D-geprint draadstuk (~15 mm) **epoxy-vast integreren** op het top-uiteinde van de stok, zorgvuldig gecentreerd en met voldoende uithardingstijd. Dit is het mannelijke deel van de schroefverbinding.
4. Na uitharding: het tech-handvat op het draadstuk schroeven. Bij goed alignement is het tech-handvat dagelijks omwisselbaar met een standaard handgreep met dezelfde mee-geprinte schroefdraad.

---

## Sectie 2 → Elektronica solderen

<p align="center">
  Elektronica-assembly van het SensePath-handvat
  <br/><em>Elektronica-assembly: XIAO ESP32-S3, DRV2605L, MG90S servo, coin vibratiemotor en audio-amp.</em>
</p>

### Volgorde (zie [wiring.md](wiring.md) voor pinout)

1. **XIAO ESP32-S3** op een mini-perfboard solderen met header-strip aan onderzijde.
2. **DRV2605L breakout** ernaast monteren.
3. **TP4056 USB-C laadcircuit** op het perfboard plaatsen.
4. **MT3608 boost converter** ernaast ; output afregelen op 5 V vóór montage. Voedt zowel de MG90S servo (altijd actief) als de MAX98357A audio-amp (opt-in, via SD-pin gegated).
5. **MAX98357A I2S versterker** plaatsen. Belangrijk: SD-pin **niet floating laten** (onbepaald gedrag). Default-stand = stand-by via 100 kΩ pull-down naar GND, met software-override via XIAO D10 (zie stap 7). GAIN-pin direct aan GND voor 15 dB max gain.
6. **I2C-bedrading** tussen XIAO en DRV2605L:
   - XIAO D4 (SDA) → DRV2605L SDA
   - XIAO D5 (SCL) → DRV2605L SCL
   - XIAO 3V3 → DRV2605L Vin
   - XIAO GND → DRV2605L GND
7. **I2S-bedrading + SD-control + GAIN** tussen XIAO en MAX98357A:
   - XIAO D6 (GPIO 43) → MAX98357A BCLK
   - XIAO D7 (GPIO 44) → MAX98357A LRC
   - XIAO D8 (GPIO 7) → MAX98357A DIN
   - **XIAO D10 (GPIO 9) → MAX98357A SD** (software gate; LOW = shutdown, HIGH = amp aan)
   - **100 kΩ weerstand** tussen MAX98357A SD-pin en GND (pull-down voor gedefinieerde boot-state)
   - **MAX98357A GAIN → direct aan GND** (één jumperdraadje, geen weerstand) voor 15 dB max gain
   - MT3608 5V → MAX98357A Vin
   - GND gemeenschappelijk

   > **Niet floating laten**: SD-pin zonder verbinding leidt tot pseudo-random kanaal-selectie (4-staats input) en pop-geluiden. De pull-down + GPIO-aansturing is essentieel.
8. **Coin vibration motor** ; 2× AWG28 draad van DRV2605L OUT+ en OUT− naar JST-PH 2-pin connector. Motor-zijde idem; polariteit is niet kritisch voor een ERM-coin motor.
9. **MG90S servo** ; standaard 3-pins JR-stekker:
   - Bruin (GND) → gemeenschappelijke GND
   - Rood (V+) → **5 V rail** uit MT3608 boost (zelfde rail als MAX98357A Vin) ; **niet** rechtstreeks aan Li-Po, want MG90S-datasheet vraagt 4.8-6 V
   - Oranje (signaal) → XIAO D9 (GPIO 8). 3.3 V PWM is voldoende voor de MG90S, geen level shifter nodig. Een 1 kΩ serie-weerstand is optioneel als defensieve GPIO-bescherming maar niet vereist
   - **Decoupling**: zet een **220-470 µF elco** tussen V+ en GND vlak bij de servo-stekker ; vangt stroompieken op zodat de XIAO niet reset
10. **HOTUT drukknop** (dubbele rol → functie + power-control via deep-sleep) ; 2-pins JST-PH connector:
    - Pin 1 (signaal) → XIAO D3 (= GPIO 4, RTC-GPIO ; vereist voor EXT0 wake-up uit deep-sleep)
    - Pin 2 → GND
    - Geen externe pull-up nodig (XIAO interne pull-up wordt in firmware geactiveerd)
11. **Geen rocker switch** in deze configuratie. TP4056 OUT+ gaat **direct** naar XIAO 5V-pad én MT3608 input. Power-control zit in de firmware (zie sectie 3 → long-press triggert deep-sleep, druk uit deep-sleep wekt opnieuw via EXT0 op D3).
12. **Speaker** ; 2-pins JST-PH connector vanaf MAX98357A speaker-output naar de mini-speaker.
13. **Batterij** ; Li-Po via JST-PH 2-pin connector aan TP4056 BAT+ / BAT−.
14. **USB-C laad-poort** ; KUOQIY 2-draads breakout (VBUS + GND) doorgelust naar TP4056 IN+ / IN−. Deze externe USB-C is **alleen voor opladen** ; firmware-flashen gebeurt via de USB-C poort op de XIAO ESP32-S3 zelf.

> De KY-040 encoder zit **niet** in het handvat. Die hangt aan de aparte controller-module ; zie [Sectie 6 → Controller-module bouwen](#sectie-6--controller-module-bouwen).

### Solder-tips

- Gebruik flux op de XIAO-pads ; klein formaat, makkelijk overspringen.
- Coin motor draden zijn dun (AWG30) ; krimpkous na elke soldeer voor trekontlasting.
- I2C-bedrading kort houden (<10 cm) om ruis te vermijden.
- I2S-bedrading idem: zo kort mogelijk, anders treedt aliasing-ruis op.
- Servo-voeding: plaats de **220-470 µF elco** tussen servo V+ en GND zo dicht mogelijk bij de servo-stekker (niet aan de MT3608-uitgang) ; daar vangt hij de korte stroompieken het effectiefst op.
- Li-Po: nooit batterij solderen onder spanning. Altijd via JST-connector aansluiten zodat ze later veilig losgekoppeld kan worden.

---

## Sectie 3 → Firmware flashen

### Arduino IDE setup

1. **Board manager URL**: `https://raw.githubusercontent.com/espressif/arduino-esp32/gh-pages/package_esp32_index.json`
2. **Install**: `esp32` board package (versie 2.0.14 of hoger).
3. **Selecteer board**: Tools → Board → ESP32 Arduino → XIAO_ESP32S3.
4. **Libraries** via Library Manager:
   - `Adafruit DRV2605 Library` (versie 1.2.x of hoger)
   - `ESP32Servo` (voor MG90S aansturing)
   - `ESP32-audioI2S` of `AudioFileSourcePROGMEM` + `AudioOutputI2S` (voor audio-fallback)
   - Eventueel `Encoder` library (Paul Stoffregen) voor KY-040, of zelf interrupt-handler schrijven

### Code

Open [../src/firmware/sensepath_esp32/sensepath_esp32.ino](../src/firmware/sensepath_esp32/sensepath_esp32.ino).

**Belangrijk**: de huidige firmware in de repo dateert van vóór de finale integratie en is geschreven voor de ESP32 DevKit. Bij de finale build moet de **handvat-firmware** code:
- I2C-pinnen aanpassen naar XIAO (SDA = 5, SCL = 6).
- Een ESP-NOW-ontvanger toevoegen die encoder-updates leest van de controller-module (zie sectie 6) en de servo-doelhoek bijwerkt.
- Een servo-aansturing via ESP32Servo aansluiten op D9.
- Een I2S-audio-pipeline opzetten op D6/D7/D8 met **D10 als SD-pin gate** (HIGH = amp aan, LOW = stand-by).
- **HOTUT-knop press-detector** (D3, RTC-GPIO 4) met onderscheid tussen short-press, double-press en long-press (≥3 s). Long-press triggert de power-down sequence:
  1. Speel een korte vibratie-cue (1 puls van 100 ms via DRV2605L) als acknowledgement
  2. `digitalWrite(AUDIO_SD_PIN, LOW)` → audio-amp in stand-by
  3. Servo naar neutraalpositie (90°), dan `servo.detach()` om PWM uit te zetten
  4. `esp_sleep_enable_ext0_wakeup(GPIO_NUM_4, 0)` → wake op falling edge van HOTUT
  5. `esp_deep_sleep_start()` → XIAO gaat slapen, ~14 µA draw

  Bij wake-up boot de XIAO opnieuw vanaf `setup()` ; geen "resume from sleep" gedrag.

De **controller-firmware** (apart project, draait op de XIAO ESP32-C3) moet de KY-040 uitlezen en via ESP-NOW de positie versturen naar het MAC-adres van de handvat-S3. Beide firmware-projecten worden los geflasht.

### Flash

1. XIAO via USB-C verbinden (de USB-C poort van het handvat dient dus dubbel ; opladen + flashen).
2. Serial Monitor openen op 115200 baud.
3. Upload via Sketch → Upload.
4. Na boot verschijnt in Serial Monitor:
   ```
   SensePath start
   DRV2605L gevonden op 0x5A
   ESP32Servo gestart op D9
   Encoder gestart op D0/D1, knop op D2
   AP gestart, IP: 192.168.4.1
   Webserver start
   ```

---

## Sectie 4 → Assembleren

1. Perfboard met XIAO + DRV2605L + TP4056 + MT3608 + MAX98357A in de handvat-core schuiven, oriëntatie zo dat de USB-C laad-poort en de HOTUT drukknop toegankelijk blijven via hun respectievelijke openingen in de cap. Geen rocker-opening meer nodig.
2. **MG90S servo** in zijn aparte cavity plaatsen, servo-as in lijn met de kompasbol-rotatie-as. Servo vastschroeven met de 2× M2-meegeleverde schroefjes.
3. **Kompasbol** op de servo-as schuiven (kruisarm-adapter), uitlijning controleren door de servo handmatig te draaien.
4. **Li-Po batterij** in zijn aparte cavity plaatsen, dubbelzijdige tape voor fixatie, JST-connector aansluiten op TP4056.
5. **Coin vibration motor** met dubbelzijdige 3M-VHB tape tegen de hypothenar-zijde van de handvat-wand fixeren (zo dicht mogelijk bij de muis-van-de-hand; dat is de meest gevoelige perceptiezone uit Develop 2).
6. **Speaker** in de cap-opening klikken, JST-connector aansluiten op MAX98357A.
7. **Cap** met 2× M3-schroeven (8 mm) sluiten.

---

## Sectie 5 → Handvat testen (los van controller)

### Functionele check (zonder controller, via WiFi-fallback)

1. Li-Po-stekker aansluiten op TP4056 ; de XIAO ESP32-S3 moet binnen ~1 s booten (LED op de XIAO knippert). Bij eerste aansluiting boot het handvat altijd op (geen latching aan/uit-mechaniek).
2. Voor losse handvat-test: smartphone WiFi → verbinden met SSID `SensePath`, wachtwoord `sensepath`. Browser → `http://192.168.4.1/`. (Voor de echte sessie: zie sectie 7 → integratie.)
3. **Coin motor test**: trigger M4 (bocht nadert) → oplopende crescendo (5 pulsen) voelbaar.
4. **Coin motor test**: trigger M6 (route-afwijking) → ademende pulsreeks (3 cycli) voelbaar.
5. **Coin motor test**: trigger M9 (batterij low) → drie korte hoog-frequente ticks.
6. **Drukknop short-press test**: HOTUT-knop kort indrukken ; status-melding in Serial Monitor (start/stop route).
7. **Drukknop long-press test**: HOTUT-knop ≥3 s ingedrukt houden ; korte vibratie-cue als acknowledgement, dan stilte (XIAO in deep-sleep). Stroommeting via USB-C inline meter moet ~10 mA draw tonen i.p.v. ~40 mA.
8. **Wake-up test**: HOTUT kort indrukken vanuit deep-sleep ; XIAO boot opnieuw, "SensePath start" verschijnt in Serial Monitor.
9. **Audio test (opt-in)**: via webcontroller audio-fallback inschakelen → MAX98357A SD-pin gaat HIGH → kort testbericht "audio actief" hoorbaar via speaker.
10. **Laadtest**: USB-C kabel in de handvat-USB-C laad-poort steken → rode LED op TP4056 (laden) brandt; volle laad → blauwe LED.

### Acceptatiecriteria handvat

- Coin motor voelbaar in de hand zonder bijgeluiden (zo niet → motor niet stevig genoeg tegen handvat-wand).
- Knop reageert binnen <50 ms voor short-press (zo niet → debounce-time-out in firmware verhogen).
- Long-press detecteerbaar bij precies 3 s ingedrukt houden ; geen accidentele triggers bij langere short-press (>500 ms maar <3 s).
- DRV2605L wordt herkend → "DRV2605L gevonden" in Serial Monitor.
- TP4056 LED's: rood bij laden, blauw bij volle accu. Handvat moet autonoom werken op Li-Po na unplug van USB-C.
- Deep-sleep current draw ~10 mA bij stroommeting (XIAO in slaap, andere componenten quiescent).

---

## Sectie 6 → Controller-module bouwen

De controller is een **fysiek aparte unit** die de testleider in de hand houdt. Klein 3D-geprint doosje (~60 × 40 × 25 mm) met de KY-040 encoder bovenaan, een rocker-switch en USB-C poort op de zijkant.

### Componenten

Zie [bom.md sectie 9 → 12](bom.md). Kort: XIAO ESP32-C3, KY-040 encoder, Li-Po 1000 mAh, TP4056 USB-C, rocker switch, USB-C laad-poort, mini perfboard.

### Soldeerstappen controller

1. **XIAO ESP32-C3** op een klein perfboard solderen met header-strip aan onderzijde.
2. **TP4056 USB-C laadcircuit** ernaast plaatsen.
3. **Voeding**:
   - TP4056 BAT+ ↔ Li-Po + (via JST-PH)
   - TP4056 BAT- ↔ Li-Po - (via JST-PH)
   - TP4056 OUT+ → rocker-switch → XIAO 5V-pad
   - TP4056 GND → gemeenschappelijke GND-bus
   - USB-C female VBUS / GND → TP4056 IN+ / IN-
4. **KY-040 encoder bedrading** (5-pins, korte draadjes):
   - Encoder + (Vcc) → XIAO 3V3
   - Encoder GND → gemeenschappelijke GND
   - Encoder CLK → XIAO D0
   - Encoder DT → XIAO D1
   - Encoder SW → XIAO D2

### Firmware controller

Aparte sketch voor de ESP32-C3. Pseudocode:

```
1. Init WiFi in station mode (geen AP) for ESP-NOW
2. Init ESP-NOW with handvat-S3 MAC-adres als peer
3. Init KY-040 pins als input met interne pull-up
4. Hardware-interrupt op encoder CLK → update absolute positie
5. Hoofdlus: elke 20 ms (~50 Hz) een EncoderUpdate-pakket versturen
```

De MAC-adres van de handvat-S3 wordt eenmalig hardcoded in de controller-sketch (of via een pairing-procedure bij eerste boot).

### Test controller los

1. Rocker AAN → XIAO C3 boot.
2. Serial Monitor (via USB-C op de C3) toont encoder-deltas terwijl je draait.
3. Controleer dat ESP-NOW pakketten verstuurd worden (success-callback prints in Serial).

### Behuizing controller

3D-geprint doosje, twee helften die met M2 of M3-schroefjes sluiten. Openingen: KY-040 encoder bovenaan (knop en knurled wiel), rocker-switch zijkant, USB-C poort zijkant.

---

## Sectie 7 → Integratie + Deliver-test

### Pairing controller ↔ handvat

1. Beide modules op AAN zetten.
2. Handvat-firmware moet "ESP-NOW receiver actief" tonen in Serial Monitor.
3. Controller-firmware moet "ESP-NOW peer geconfigureerd" tonen.
4. Encoder draaien op de controller → de servo in het handvat moet 1-op-1 meedraaien binnen ~100 ms.

### Volgende stap → echte testsessie

Wizard-of-Oz testsessie opzetten met een echte gebruiker. Zie [reports and protocols/protocol_sensepath_develop3_PDF.pdf](../reports%20and%20protocols/protocol_sensepath_develop3_PDF.pdf) voor het testprotocol dat we eerder gebruikten. Voor de Deliver-validatie: testleider houdt de controller-module vast en draait de KY-040 encoder terwijl hij of zij achter de gebruiker loopt, en de blinde gebruiker volgt het mechanisch kompas + de drie haptische cues op een onbekende route. De controller-module zorgt dat de testleider niet langer een telefoon-webpagina hoeft te bedienen ; rotatie is fysiek, direct, met haptische klik per stap.

---

## Troubleshooting

| Symptoom | Vermoedelijke oorzaak | Fix |
|---|---|---|
| DRV2605L niet gevonden | I2C-bedrading gekruist, of pinnen niet ingesteld | Pinout checken in [wiring.md](wiring.md), I2C-scanner sketch draaien |
| Coin motor voelt zwakjes | Motor niet stevig tegen handvat-wand | Meer VHB-tape, of motor verplaatsen naar hypothenar-zijde |
| Servo trilt of jittert | Voeding instabiel (te kleine of geen elco), of PWM-signaal te dichtbij ruisbron | Vergroot decoupling cap naar 220-470 µF op servo V+-lijn, plaatsen vlak bij servo-stekker. Signaaldraad weghouden van I2S-lijnen |
| XIAO reset bij servo-beweging | Stroompiek van servo doet 5 V rail kortstondig inzakken | Decoupling-elco vergroten of dichter bij servo zetten ; eventueel MT3608 output checken op 5.0 V (niet 4.5 V) |
| Encoder slaat stappen over | Debounce-tijd te kort of interrupts niet geconfigureerd | Hardware-interrupt op CLK gebruiken (`attachInterrupt`) ipv polling |
| Knop registreert dubbel | Debounce te kort | `BUTTON_DEBOUNCE_MS` in firmware naar 50 ms verhogen |
| WiFi AP niet zichtbaar | XIAO niet juist geboot | Serial Monitor checken, eventueel reset-knop |
| Audio ruis of vervormd | Boost converter niet stabiel op 5 V, of I2S-pinnen gekruist | Boost-uitgang met multimeter checken, I2S BCLK/LRC pinout verifiëren |
| Trilling vibrato/onstabiel | Power-supply ruis | Decoupling cap op DRV2605L Vin (10 µF) |
| Handvat laadt niet op USB-C | TP4056 IN+/IN− niet correct doorgelust | USB-C breakout-board pinout checken, polariteit verifiëren |
| Handvat schakelt uit kort na boot | Li-Po onder discharge-cutoff | Opladen ; TP4056 schakelt uit onder ~2.5 V om de accu te beschermen |
| Handvat gaat niet in deep-sleep bij long-press | Long-press detectie niet ingebouwd, of `esp_sleep_enable_ext0_wakeup` niet correct geconfigureerd | Firmware long-press timer checken (≥3 s), `esp_deep_sleep_start()` aanroep verifiëren, RTC-GPIO 4 als wake-pin bevestigen |
| Handvat wakkert niet uit deep-sleep | EXT0 wake-up trigger niet armed of HOTUT niet correct bedraad | `esp_sleep_enable_ext0_wakeup(GPIO_NUM_4, 0)` aanroepen vóór `esp_deep_sleep_start()`, HOTUT pin-bedrading naar D3 verifiëren |
| Hoge stroom in "uit"-stand (>20 mA) | XIAO niet in echte deep-sleep, of MT3608 trekt te veel quiescent | Serial Monitor uitlezen tijdens transitie, MT3608 quiescent meten met multimeter (verwacht ~1-3 mA) |

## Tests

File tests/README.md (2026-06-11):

# Tests → SensePath

Deze map bevat de testbeschrijvingen en -resultaten van het SensePath project. Voor de uitgebreide protocollen en rapporten: zie [reports and protocols/](../reports%20and%20protocols/).

---

## Test-strategie van het project

SensePath is gevalideerd via **gebruikersonderzoek met echte deelnemers** (in totaal N=15+ over zes test-waves), niet via geautomatiseerde unit- of integratietests op de firmware. De keuze daarvoor is bewust: voor een haptisch interactie-product is de perceptie door de doelgroep de primaire kwaliteitsmaat; firmware-correctheid is een randvoorwaarde maar geen succes-criterium.

| Wave | Fase | N | Type test | Rapport |
|---|---|---|---|---|
| Wave 1 | Definition | 5 | Conceptvalidatie | [Report_define_WAVE1.pdf](../reports%20and%20protocols/Report_define_WAVE1.pdf) |
| Wave 2 | Definition | 5 | Verfijning + MoSCoW | [Report wave 2.pdf](../reports%20and%20protocols/Report%20wave%202.pdf) |
| Develop 1 | Develop | 5 | Functionele tests | [Report_SensePath_Devolop_1.pdf](../reports%20and%20protocols/Report_SensePath_Devolop_1.pdf) |
| Develop 2 | Develop | 5 | Usability + ergonomie | [Rapport_Dev2_PDF.pdf](../reports%20and%20protocols/Rapport_Dev2_PDF.pdf) |
| Develop 3 | Develop | 5 (3 blind + 2 ziend) | Microinteracties + CMF + Wizard-of-Oz | [rapport_sensepath_develop3.pdf](../reports%20and%20protocols/rapport_sensepath_develop3.pdf) |
| Deliver | Deliver | TBD | Autonome wandeling + GPS-validatie | TODO ; gepland |

---

## Firmware-validatie (handmatig)

De firmware in [src/firmware/sensepath_esp32/](../src/firmware/sensepath_esp32/) is getest via:

1. **I2C-scanner sketch** ; bevestigt dat de DRV2605L op adres 0x5A reageert.
2. **Wizard-of-Oz webcontroller** ; elke microinteractie (M1 → M9) handmatig getriggerd via `http://192.168.4.1/`.
3. **Empirische validatie tijdens user tests** ; de drie kernsignalen (M4, M6, M9) werden per gebruiker beoordeeld op herkenbaarheid en cognitieve belasting.

Geen geautomatiseerde unit tests of CI-pipeline. Voor de Deliver-fase staat een trillingsduur- en amplitude-validatie via oscilloscoop op de planning, om de DRV2605L-output objectief te kwantificeren.

---

## Toekomstig werk

Voor wie dit project zou verderzetten:

- **Geautomatiseerde pattern-tests**: een referentie-oscilloscoop + capture-script om de M4/M6/M9 trillingen te verifiëren tegen een golfvorm-spec.
- **Hardware-in-the-loop simulatie**: een mock-DRV2605L op SPI/I2C-bus om de firmware zonder fysieke motor te testen.
- **End-to-end veld-tests**: scripts om GPS-input (mock of echt) door het systeem te leiden en de uitgevoerde microinteracties te loggen, bedoeld voor reproduceerbare regressies.

Deze items vallen buiten de scope van het Develop 3 prototype maar worden hier genoteerd als roadmap.

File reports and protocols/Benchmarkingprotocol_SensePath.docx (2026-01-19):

# Benchmarkingprotocol

Projectnaam: Spatial experiences for visually impaired people

Onderzoeker: Sam Piryns, sam.piryns@ugent.be

Context & doelgroep: Volledig blinde personen die regelmatig publieke gebouwen bezoeken (stations, campussen, overheidsgebouwen, zorginstellingen…).

# 1. Doelstelling en kadering

Doel: systematisch vergelijken van bestaande (indoor) navigatie‑oplossingen voor blinden en slechtzienden om ontwerpkeuzes te onderbouwen. Sterktes worden best practices; zwaktes worden designopportuniteiten.

# 2. Onderzoeksvragen

1. Welke oplossingen bestaan er vandaag voor oriëntatie en navigatie in publieke gebouwen (inclusief vormfactor en infrastructuur)?

2. Hoe verschillen ze qua feedback (audio/haptisch), nauwkeurigheid, schaalbaarheid/kost en toegankelijkheid?

3. Welke trade‑offs kunnen geadresseerd worden (bv. infra‑vrij navigeren met robuuste guidance)?

4. Welke onderliggende technologieën en lokalisatiemethoden gebruiken huidige indoor-navigatieoplossingen voor blinden, en hoe beïnvloeden die de nauwkeurigheid, robuustheid, infrastructuurbehoefte?

• WeWALK SmartCane 2 — https://wewalk.io/en/guide/ ; https://wewalk.io/en/product/

• Sunu Band — https://lowvisionmd.org/sunu-band-2/

• feelSpace naviBelt — https://feelspace.de/en/

• Biped NOA (vest) — https://www.exobot.ca/noa-by-bipedai

• 7Sense SuperBrain — https://enviter.eu/webinar-superbrain-telehaptic-device/

• NaviLens — https://www.rnib.org.uk/living-with-sight-loss/assistive-aids-and-technology/navigation-and-communication/navilens/

• Wayfindr (open standaard, geen product) — https://www.wayfindr.net/

• GoodMaps (Indoor/Explore) — https://goodmaps.com/ ; paper: https://openaccess.cms-conferences.org/publications/book/978-1-964867-37-3/article/978-1-964867-37-3_9

• RightHear — https://www.right-hear.com/howitworks/ ; https://www.right-hear.com/

• Waymap — https://www.waymapnav.com/

• .lumen — https://dotlumen.com/

• eZwayZ - https://www.ezwayz.com/

• Lokalisatiemethode

• Sensorfusie & algoritmen

• Benodigde infrastructuur

• Nauwkeurigheid & robuustheid

• Feedbackmodaliteit

• Schaalbaarheid & beheer

• Rijpheid (TRL) & praktijkcases

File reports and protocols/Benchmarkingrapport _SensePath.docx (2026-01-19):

# Benchmarkingrapport (n = 11)

Benchmarking is een methode uit het user-centered design (UCD) traject waarbij bestaande oplossingen systematisch worden vergeleken met toonaangevende voorbeelden. Door producten en diensten op relevante criteria naast elkaar te zetten wordt er inzicht in sterke en zwakke punten en in ontbrekende functionaliteit verkregen.

Voor navigatie in publieke gebouwen voor blinden en slechtzienden zijn er dertien aspecten geïnventariseerd, waaronder:

- soorten navigatie-informatie (bijvoorbeeld routebeschrijvingen, aangegeven punten van interesse, contextuele oriëntatie),
- modaliteiten van feedback (audio, haptisch, braillescherm etc.),
- vereiste infrastructuur of hardware (zoals beacons, visuele codes, sensoren),
- gebruikssituaties (binnen vs. buiten, openbaar vervoer, gebouwen),
- kosten en schaalbaarheid van de oplossing.

Vervolgens hebben we gezocht naar innovatieve systemen die al bestaan voor toegankelijk navigeren. De werking van elk systeem, van sensorinput tot output is beschreven. Daarna vergelijken we de tien geselecteerde producten systematisch op hun aanpak, sterke punten, beperkingen, gebruiksvereisten en relevantie voor indoor navigatie. Ten slotte trekken we concrete ontwerprichtingen en -implicaties uit deze vergelijking: waar liggen nog gaten in de oplossingen, en welke formfactors, infrastructuren en feedbackmodaliteiten lijken het meest veelbelovend voor een nieuw ontwerp?

## WeWALK SmartCane 2

De WeWALK SmartCane 2 is een slimme ‘witte stok’ die traditionele obstakeldetectie combineert met navigatie via een smartphone. In de stok zit een ultrasone sensor die obstakels op hoofd- of borsthoogte meet[2] (https://wewalk.io/en/guide/). Wanneer de stok een obstakel detecteert, geeft het handvat sterke vibraties (haptische feedback) en audio-waarschuwingen via de ingebouwde speaker[3][4] (https://wewalk.io/en/product/). De gebruiker kan via knoppen een spraakassistent activeren om bijvoorbeeld bestemmingen in te stellen.

Voor routenavigatie wordt de stok draadloos met een smartphone gekoppeld. De app levert GPS-gestuurde, stap-voor-stap instructies. Hierdoor krijgt de gebruiker turn-by-turn begeleiding (‘clock directions’) en informatie over bezienswaardigheden en openbaar vervoer langs de route[5] (https://wewalk.io/en/guide/)[6] (https://wewalk.io/en/product/). Deze audiogeleide navigatie komt uit een ingebouwde speaker, zodat het niet nodig is de telefoon te hanteren[7]. Volgens de fabrikant detecteert de SmartCane zelfs hoger liggende hindernissen (bijvoorbeeld laaghangende takken) en stuurt het deze informatie naar de gebruiker via vibraties en gesproken instructies[3] (https://wewalk.io/en/guide/)[4] (https://wewalk.io/en/product/).

Kortom, WeWALK fungeert als een multi-sensoren stokkie: het behoudt de mechanische functie van een blindencane, maar voegt er sensoren en een luidspreker aan toe. De gebruiker krijgt dus zowel ‘klassieke’ cane-feedback (door contact met de grond) als extra melding voor bovengrondse obstakels. Sterke punten zijn de handsfree navigatie en stemassistent, maar het systeem vereist wel de aanschaf van de gespecialiseerde stok (prijs ca. €850) en een smartphone.

## Wearable armbanden – Sunu Band en FeelSpace naviBelt

Sunu Band (polsband): De Sunu Band is een draagbare sonarband voor om de pols. Hij gebruikt echolocatie (soort sonar) om objecten binnen ongeveer 5,5 meter afstand te detecteren[8] (https://lowvisionmd.org/sunu-band-2/). Wanneer er een obstakel in de buurt is, trilt de band meer of minder sterk om de afstand aan te geven (haptische feedback)[8] (https://lowvisionmd.org/sunu-band-2/). Daarnaast fungeert de Sunu Band als een soort ‘haptisch kompas’: via een smartphone-app kan de gebruiker een richting instellen (bijvoorbeeld een navigatieroute of een zoekfunctie naar points-of-interest), waarna de band leidt door subtiele trilsignalen. De band bevat extra sensoren (zoals magnetometer) voor kompasfunctie, GPS-ondersteuning en live-updates via een app[9] (https://lowvisionmd.org/sunu-band-2/). Zo kan een blinde gebruiker zich oriënteren zonder de telefoon continu te hoeven zien. Het is een licht en draagbaar hulpmiddel, maar het is primair gericht op obstakeldetectie en geeft zelf geen gedetailleerde routecoördinaten tenzij gekoppeld aan een app.

feelSpace naviBelt (heupband): De naviBelt is een vibrotactiele band die om de taille wordt gedragen. Hij bevat 16 trillende elementen rondom de buik, waardoor 360° omgevingsinformatie kan worden overgebracht[10] (https://feelspace.de/en/). Zonder appfunctie fungeert de riem als een ‘tactiele kompas’: hij toont de richting van het noorden of een vooraf ingestelde richting via vibraties aan de voorkant van de buik. Met een smartphone-app (‘feelSpace app’) kan de gebruiker een bestemming ingeven. Eenmaal verbonden via Bluetooth geeft de riem dan geleidingsinformatie: bijvoorbeeld een trillend element aan de voorzijde betekent ‘rechtdoor’ en als het signaal naar links of rechts verschuift, moet de gebruiker die kant op gaan[11] (https://feelspace.de/en/).

De feelSpace naviBelt vergroot het ruimtebewustzijn zonder dat de gebruiker continu naar audio hoeft te luisteren. De haptische feedback is stil en subtiel, en laat handen en oren vrij. Nadelen zijn dat het een extra apparaat is om om te doen en dat de huidige implementatie vooral werkt voor 1e-persoonsrichtingen (er zijn geen gesproken instructies). Bij beide armbanden/gordels ligt de nadruk op intuitieve, continue haptische informatie over de omgeving[10] (https://feelspace.de/en/)[8] (https://lowvisionmd.org/sunu-band-2/).

## Biped NOA (smart vest)

De Biped NOA is een vestachtig wearable van het bedrijf Biped.ai, ontwikkeld als ‘AI co-piloot’ bij oriëntatie. Het bevat een breedhoeksensor (ongeveer 170°) met meerdere dieptecamera’s (3D-‘vision’) die tot zo’n 10 m omgevingshoge obstakels in kaart brengt[12] (https://www.exobot.ca/noa-by-bipedai). Door kunstmatige intelligentie kan het systeem bewegende en stilstaande objecten herkennen en mogelijke botsingen voorspellen.

In plaats van haptiek geeft NOA audiofeedback via botgeleiding (bone-conduction oortjes), zodat de gebruiker zelf de omgeving kan blijven horen. De instructies zijn spraakberichten die nauwkeurig zeggen in welke richting gelopen moet worden[12] (https://www.exobot.ca/noa-by-bipedai)[13] (https://www.exobot.ca/noa-by-bipedai). Naast obstakeldetectie heeft NOA een GPS-navigatiecomponent: de gebruiker krijgt stapsgewijze routebegeleiding zelfs buiten of in grote gebouwen. Bovendien kan het contextuele informatie geven, zoals de aanwezigheid van deuren of oversteekplaatsen (omgeving beschrijven), zodat nieuwe locaties beter te begrijpen zijn[12] (https://www.exobot.ca/noa-by-bipedai)[13] (https://www.exobot.ca/noa-by-bipedai).

NOA is met circa 950 g relatief licht en ontworpen om discreet onder een jas of op de rug gedragen te worden[14] (https://www.exobot.ca/noa-by-bipedai). Het vereist wel een complete exoskelet-achtige installatie (vest met sensorunit en oortjes). Voordeel is een zeer uitgebreide, handsfree begeleiding zonder additionele infrastructuur. Nadeel zijn de kosten en complexiteit van het apparaat: het is duurder en omvangrijker dan een simpele stok of band. Voor indoor-navigatie kan NOA bruikbaar zijn als er betrouwbare (offline) kaartdata is; het richt zich vooral op buiten en grote open ruimtes, maar theoretisch kan het ook routebeschrijving binnen realiseren via stappen tellen en oriëntatie met de sensoren.

## .lumen Glasses

De .lumen glasses zijn slimme brillen ontwikkeld door het Roemeense bedrijf .lumen. Ze bootsen de rol van een ‘geleidehond’ na met autonome voertuigtechnologie. In de bril zijn meerdere dieptecamera’s en beeldsensoren (vergelijkbaar met Intel RealSense) geïntegreerd, samen met krachtige AI-software (genaamd PAD AI: Pedestrian Autonomous Driving)[15] (https://ispr.info/2025/01/17/lumen-ai-glasses-help-blind-navigate-without-canes-or-guide-dogs/). Deze technologie maakt in realtime een 3D-kaart van de omgeving. De software herkent bijvoorbeeld stoepen, zebrapaden, trappen en obstakels, zonder dat daarvoor voorafgaande gedetailleerde kaarten nodig zijn[15] (https://ispr.info/2025/01/17/lumen-ai-glasses-help-blind-navigate-without-canes-or-guide-dogs/).

Op basis van die omgevingsscan berekent .lumen veilige routes. Via lichte vibraties in de bril (haptische signalen) leidt het systeem de gebruiker: vergelijkbaar met hoe een geleidehond zou ‘trekken’ richting het doel[16] (https://ispr.info/2025/01/17/lumen-ai-glasses-help-blind-navigate-without-canes-or-guide-dogs/). Bij belangrijke situaties (bijvoorbeeld een trap of drukke weg oversteken) geeft de bril juist audio-instructies/waarschuwingen. De bril integreert met Google Maps: de gebruiker kan een bestemming op de telefoon instellen, waarna .lumen de route tot aan de deur berekent en wijst[16] (https://ispr.info/2025/01/17/lumen-ai-glasses-help-blind-navigate-without-canes-or-guide-dogs/).

Kortom, .lumen combineert geavanceerde visuele sensoren en AI om een veilige wandelroute te plannen, en geeft zowel subtiele vibratieaanwijzingen als spraakmeldingen. Het richt zich vooral op complexe buitenomgevingen, maar zou in principe ook in grote binnenruimtes toepasbaar zijn. Het vereist wel de aankoop van de speciale bril (nog in prototypische fase) en enige rekenkracht, maar het is relatief ‘zelfvoorzienend’: geen extra zenders of codes nodig. Dit systeem toont dat intensieve machine-vision en autonome planning de traditionele hulpmiddelen kunnen vervangen[17] (https://ispr.info/2025/01/17/lumen-ai-glasses-help-blind-navigate-without-canes-or-guide-dogs/)[16] (https://ispr.info/2025/01/17/lumen-ai-glasses-help-blind-navigate-without-canes-or-guide-dogs/).

## 7Sense SuperBrain (Telehaptic Sight)

De SuperBrain 1 van 7Sense (Estland) is een experimenteel haptisch draagbaar apparaat – soms Telehaptic Sight genoemd. Het heeft een matrix van trilsignalen (tiny vibromotors) die tegen het voorhoofd rusten. Via meerdere sensoren (dieptesensor, HD-camera en optioneel thermische camera) ‘voelt’ het systeem de omgeving. Wat de gebruiker ziet (of niet ziet) wordt vertaald in voelbare patronen op het hoofd[18] (https://enviter.eu/webinar-superbrain-telehaptic-device/).

In simpele woorden: de drager kan via de trilmatrix voorwerpen, bewegingen en afstanden in de omgeving ‘voelen’ op het voorhoofd[18] (https://enviter.eu/webinar-superbrain-telehaptic-device/). AI herkent bijvoorbeeld nabij personen en obstakels, en zet die om in intuïtieve vibratiepatronen. De ontwikkelaars benadrukken dat dit meer is dan alleen obstakelwaarschuwing: het is bedoeld om interacties met mensen en objecten ‘haptisch’ mogelijk te maken. Bovendien gebruikt het systeem kunstmatige intelligentie om objectherkenning uit te voeren, waarmee het de veiligheid en ruimtelijke oriëntatie verbetert[19] (https://enviter.eu/webinar-superbrain-telehaptic-device/).

De SuperBrain is uniek in zijn vormfactor: in plaats van audio gebruikt het haptische output op het lichaam. Het laat oren vrij en trekt geen extra aandacht. Nadeel is de complexiteit van interpretatie: de gebruiker moet leren wat de trilsignalen betekenen. Het apparaat zit nog in onderzoeksfase en is niet wijd verspreid. Het richt zich primair op het bieden van een extra ‘gevoelszin’ voor de blinde gebruiker.

## NaviLens

NaviLens is een systeem van optische codes (vergelijkbaar met grote gekleurde QR-codes) die in de openbare ruimte worden opgehangen, bijvoorbeeld in stations, musea of haltes. Elke code bevat een unieke informatiepatroon van gekleurde vierkanten. De visuele codes hebben geen stroom en zenden geen signaal uit: ze worden gewoon gefotografeerd door de smartphonecamera.

De gebruiker opent de NaviLens-app en richt de camera in de richting van een code. Het slimme algoritme herkent automatisch de code, ook wanneer de gebruiker niet precies richt of in beweging is[20] (https://www.rnib.org.uk/living-with-sight-loss/assistive-aids-and-technology/navigation-and-communication/navilens/). Binnen enkele meters afstand kan de app al detecteren welke code er is en wat die betekent. De informatie wordt vervolgens zowel visueel, spraakzaam als via trillingen (haptisch) gecommuniceerd. Zo kan NaviLens zowel statische info (zoals “dit is de ingang” of “museumzaal 3”) als dynamische info (busvertrektijden, noorderbreedte) overbrengen[20] (https://www.rnib.org.uk/living-with-sight-loss/assistive-aids-and-technology/navigation-and-communication/navilens/)[21] (https://www.rnib.org.uk/living-with-sight-loss/assistive-aids-and-technology/navigation-and-communication/navilens/).

Belangrijk is dat de codes in een brede hoek zichtbaar zijn (camera’s herkennen codes tot 160–180° omtrek[20] (https://www.rnib.org.uk/living-with-sight-loss/assistive-aids-and-technology/navigation-and-communication/navilens/)). Daardoor hoeft de gebruiker niet recht vóór de code te staan: het kan van opzij of schuin gezien worden. Het systeem geeft ook (via audio/haptiek) relatieve afstandsinformatie en navigeert naar belangrijke punten zoals ingangen en toiletten[21] (https://www.rnib.org.uk/living-with-sight-loss/assistive-aids-and-technology/navigation-and-communication/navilens/).

NaviLens vereist alleen het ophangen van de gekleurde codes, en het gebruik van een smartphone met de app. Het is relatief goedkoop en schaalbaar (geen actieve hardware nodig)[20] (https://www.rnib.org.uk/living-with-sight-loss/assistive-aids-and-technology/navigation-and-communication/navilens/). Een nadeel is dat het afhankelijk is van het aanbrengen van codes door beheerders. Maar in een beklede omgeving (stations, openbare gebouwen) biedt NaviLens een krachtige manier om veel informatie toegankelijk te maken voor blinden.

## Wayfindr (Open standaard voor audio-navigatie)

Wayfindr is geen product maar een open standaard en toolkit voor audio-binnen-navigatie, ontwikkeld door RSLB (UK) en UsTwo. Het beschrijft hoe gebouwen navigatie-informatie kunnen aanbieden via Bluetooth-beacons en apps. In de Wayfindr-architectuur worden kleine BLE-beacons op strategische plekken geïnstalleerd (bijvoorbeeld bij ingangen, kruispunten, perrons). Een mobiele app (Wayfindr of partner-app) detecteert deze beacons om de locatie te bepalen, en speelt vervolgens gepersonaliseerde audio-instructies af. Dit zijn beknopte gesproken route-instructies, bijvoorbeeld “Ga 10 meter rechtdoor en sla linksaf” zodra de gebruiker een volgend kruispunt bereikt.

Het doel is consistenter en inclusief: alle locaties hanteren dezelfde richtlijnen voor gesproken instructies en beacon-plaatsing. Wayfindr claimt de eerste internationaal erkende standaard voor dit soort audio-navigatie[22] (https://www.wayfindr.net/). In praktijk zijn al proeven gedaan in metro’s en winkelcentra.

Belangrijk kenmerk is dat Wayfindr zelf geen nieuwe hardware ontwikkelt – het is richtlijnen. Het kan technisch gekoppeld zijn aan gangbare BLE-beacons (bijv. iBeacon of Eddystone). De gebruiker hoeft alleen de Wayfindr-app op een smartphone te installeren. Sterk punt is de gestandaardiseerde aanpak voor binnenruimten, inclusief duidelijk gedefinieerde audio-inhoud. Limiet is de afhankelijkheid van bruikbare infrastructuur: een gebouw moet de beacons plaatsen en een gedetailleerde kaart aanleveren.

## GoodMaps (Indoor navigatie-app)

GoodMaps is een indoor-navigatiesysteem dat werkt met een gewone smartphone en geavanceerde computer vision. Het Amerikaanse project gebruikt LiDAR-scans (point clouds) en camera’s om eerst nauwkeurige digitale plattegronden van gebouwen te maken[23] (https://goodmaps.com/). Deze kaarten worden met behulp van AI (computer vision-algoritmen) en crowd-sourcing semiautomatisch opgebouwd en up-to-date gehouden[24] (https://openaccess.cms-conferences.org/publications/book/978-1-964867-37-3/article/978-1-964867-37-3_9).

Gebruikers installeren de GoodMaps-app en kunnen binnen complexe gebouwen (bijv. luchthavens, universiteiten, warenhuizen) naar een doel navigeren. De app geeft dan spraak- of tekstinstructies per stap. Cruciaal is dat GoodMaps de telefoon-sensoren en camera realtime gebruikt om de positie te schatten: het systeem herkent overgangen tussen zones of oriënteert zich aan architectuurelementen. Hierdoor kan het nauwkeurig navigeren zonder dat er in het gebouw extra beacons nodig zijn[24] (https://openaccess.cms-conferences.org/publications/book/978-1-964867-37-3/article/978-1-964867-37-3_9). Volgens onderzoekers gebruikt GoodMaps AI om de camera-input te verwerken en de gebruiker zelfs “zonder zicht” door de ruimte te loodsen[24] (https://openaccess.cms-conferences.org/publications/book/978-1-964867-37-3/article/978-1-964867-37-3_9).

Voordelen van GoodMaps zijn dus de hoge nauwkeurigheid en het ontbreken van hardware-installatie (in tegenstelling tot Wayfindr). Nadeel is dat het voor elk gebouw initiële kaartdata vraagt en dat het afhankelijk is van een goed werkende camera-invoer (die kan lastig zijn bij fel zonlicht of reflecties). De app biedt concrete turn-by-turn begeleiding op veel punten: “daar linksaf” en “vervolg richting entree” via audio, wat het heel relevant maakt voor indoor navigatie[24] (https://openaccess.cms-conferences.org/publications/book/978-1-964867-37-3/article/978-1-964867-37-3_9).

## RightHear (Talking Signage)

RightHear is een Israëlische indoor-navigatieservice die werkte met een netwerk van ‘talking signs’. Bedrijven integreren drie componenten: een online portal, fysieke spots (beacons of markers) in de ruimte, en een gratis smartphone-app voor bezoekers. In het portal zetten beheerders audio-beschrijvingen klaar voor specifieke locaties (bijvoorbeeld een vitrinekast, toiletten, liftschachten). Vervolgens plaatsen ze ofwel kleine batterijgevoede Bluetooth-beacons of visuele markeringen (‘RightHear markers’) op die punten.

De app van de gebruiker scant via Bluetooth of locatie (GPS) welke spot in de buurt is en speelt automatisch het bijbehorende audiobericht af[25] (https://www.right-hear.com/howitworks/). Op die manier „lezen” de omgevingspunten als het ware de omgeving voor. Volgens de makers werkt het zonder WiFi of vaste stroomvoorziening[25] (https://www.right-hear.com/howitworks/). De spots kunnen ook promotionele informatie afspelen of routes voorstellen in gebouwen. Het systeem is dus vooral informatief: het meldt letterlijk wat er op een plaats te zien is.

RightHear is eenvoudig te installeren voor bedrijven en biedt ondersteuning voor tientallen talen[26] (https://www.right-hear.com/howitworks/). Het is minder een routeplanner en meer een dynamisch bewegwijzeringssysteem. Het voordeel is een laagdrempelige audio-oriëntatie zonder dat de gebruiker zelf op knoppen hoeft te drukken. Nadeel is dat het enerzijds niet per se “naar een doel toe” leidt, en anderzijds dat de locatievinding soms onnauwkeurig is (bluetooth-bereik kan variëren). Toch heeft RightHear inmiddels duizenden locaties wereldwijd uitgerold[27] (https://www.right-hear.com/).

## Waymap (Audio-navigatie zonder infra)

Waymap is een Britse app die zonder enige extra infrastructuur stapsgewijze navigatie biedt, ook binnenshuis en zelfs diep ondergronds. Cruciaal is dat Waymap alleen de ingebouwde sensoren van de smartphone gebruikt (versnellingsmeter, gyroscoop) plus een bekend algoritme. De gebruiker start Waymap, stelt een eindbestemming in (bijvoorbeeld een perron, kamer of loket), en houdt de telefoon of zijn hoofd in één richting. De app telt tijdens het lopen de stappen en combineert dat met de richting (kompas) en bewegingen. Hiermee rekent hij de positie nauwkeurig uit.

Een belofte is “nauwkeurig tot op een stap”[28] (https://www.waymapnav.com/). De navigatie-instructies zijn volledig gesproken en hoofdzakelijk stap-voor-stap: “loop 12 stappen vooruit, sla linksaf” etc. Volgens de makers is geen GPS, WiFi, Bluetooth of infrastructuur nodig: alleen de bewegingssensoren van het toestel[29] (https://www.waymapnav.com/)[30] (https://www.waymapnav.com/). De omgeving (plattegrond) moet wel van tevoren digitaal ingevoerd zijn, zodat de app weet waar muren en paden liggen.

Het voordeel van Waymap is dus nul-hardware-behoefte – er hoeven geen beacons of codes te worden geïnstalleerd[30] (https://www.waymapnav.com/). Het werkt zelfs underground (stationstunnels, winkels). Het nadeel is dat het nog erg experimenteel is en afhankelijk van kalibratie: kleine tel- of meetfouten kunnen na verloop van tijd optellen.

Maar conceptueel biedt Waymap een ongebruikelijke vormfactor: navigatie door simpelweg de telefoon in de zak te doen en de instructies te beluisteren[29] (https://www.waymapnav.com/).

## eZWayz

eZwayZ is een nederlands indoor-navigatiesysteem dat werkt met een gewone smartphone en beaconless visual positioning. De app gebruikt de camera (in combinatie met IMU-sensoren) om live beelden te vergelijken met een vooraf aangemaakte digitale 3D-kaart (digital twin) van het gebouw. Op die manier kan eZwayZ de positie en kijkrichting van de gebruiker bepalen zonder Bluetooth-beacons of andere extra infrastructuur.

Gebruikers installeren de eZwayZ-app en kunnen binnen complexe gebouwen (zoals musea, stations, campussen of kantoren) een bestemming kiezen. De app geeft vervolgens turn-by-turn begeleiding via spraak en haptische trillingen (ears-free mogelijk). Cruciaal is dat eZwayZ de telefoonsensoren en camera realtime inzet om overgangen te herkennen (bijv. deurzones, trappen, liften) en de route te volgen ten opzichte van de indoor kaart. Daardoor kan de app nauwkeurig navigeren zonder dat er beacons geplaatst moeten worden.

Voordelen van eZwayZ zijn de hoge nauwkeurigheid zonder hardware-installatie en de combinatie van audio + haptiek, waardoor navigatie discreet en oren-vrij kan blijven. De haptisch navigatie wordt via de telefoon geïmplementeerd, navigatie gebeurd op basis gekoppelde trillingen bijvoorbeeld: 1 korte trilling = rechts, 2 korte trillingen = links.Een belangrijk aandachtspunt is dat elk gebouw eerst gemapt moet worden (digital twin opbouwen en onderhouden) en dat de robuustheid mede afhangt van camera-condities (licht, reflecties). De app ondersteunt concrete turn-by-turn instructies (“hier linksaf”, “volg de gang tot de balie”), wat haar bijzonder relevant maakt voor indoor navigatie door blinden en slechtzienden.
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

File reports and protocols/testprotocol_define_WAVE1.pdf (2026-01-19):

# Testprotocol – Wave 1

Vak: Project Gebruiksgericht Ontwerpen
Academiejaar: 2025–2026

Onderzoekers: Sam Piryns, Titus Impens, Han Deburchgraeve

## 1. Projectinformatie

Projectnaam: SensePath – Smart Handle voor de witte stok

SensePath is een slimme handgreep die op een bestaande lange witte stok wordt bevestigd. De handle moet:

- eenvoudig en intuïtief te monteren/demonteren zijn op verschillende white canes;
- haptische feedback geven over richting en omgeving, zonder de bestaande informatie van de stok te verliezen of gebruikers te overbelasten.
- Hele pipeline moet gebruiksvriendelijk en doelgericht te gebruiken zijn

In Wave 1 testen we vroege concepten rond handvatgebruikt, haptiek en gebruikconcept nog zonder definitieve vormgeving of technologie.

## 2. Doelstelling en kadering

Na de discoveryfase, waarin we de context, behoeften en problemen van witte-stokgebruikers in kaart brachten, start in deze Wave 1 de definefase.
In deze eerste testronde ligt de focus op functionele concepten, niet op details.

Doel van Wave 1

1. Achterhalen of een “smart handvat” op de stok voor gebruikers zinvol is t.o.v. alternatieven, en welke randvoorwaarden daarbij cruciaal zijn (bv. variatie in stokken, meerdere stokken, eventuele toepassing bij geleidehond).
2. Achterhalen welk type haptische feedback gebruikers het duidelijkst, prettigst en meest vertrouwenwekkend vinden.
3. Achterhalen welk gebruiksconcept (smartphonegebruik, startlocatie, manier van bestemming kiezen, bediening, extra functies) het beste aansluit bij de voorkeuren en routines van witte-stokgebruikers.

De resultaten worden gebruikt om 1–2 richtingen per thema te selecteren en te verfijnen in Wave 2.

## 3. Onderzoeksvragen

### 3.1 Conceptueel handvat vs volledige stok

1. In welke mate ziet de gebruiker een meerwaarde in een smart handvat t.o.v. een klassieke witte stok (met/zonder smartphone-app)? Welke voordelen en bezorgdheden komen hierbij naar voren (comfort, veiligheid, betrouwbaarheid, mentale belasting)?

2. Hoe sterk variëren stokken in de praktijk (type, diameter, vouwstok vs vaste stok, tip/handgreep)? Gebruikt de gebruiker meerdere stokken en hoe belangrijk is compatibiliteit met meerdere stokken voor adoptie en dagelijks gebruik?
3. Is het concept ook relevant of zelfs beter op een andere drager dan de stok (bv. geleidehond band/harnas of pols/arm)? Welke eisen en dealbreakers gelden daar (storend, onveilig, interfereert met handelingen)?

### 3.2 Haptische feedback via de handle

1. Welk type haptische feedback (mechanisch balletje, trilmotoren, lineaire actuatoren) heeft de voorkeur om richting en omgevingsinformatie over te brengen?
2. Bij welk concept voelen gebruikers zich het meest zeker over de betekenis van de signalen (links / rechts / vooraan / urgentie)?
3. Welke eigenschappen (locatie op de hand, intensiteit, duur, patroon, rustig vs. “agressief”) vinden gebruikers positief of storend?

### 3.3 Concept & gebruiksworkflow

1. Hoe willen gebruikers dat het geïntegreerd wordt in hun dagelijkse mobiliteit met de witte stok (waar, wanneer en in welke situaties..)
2. Welke rol moet de smart handle spelen in verhouding tot de smartphone en andere bestaande hulpmiddelen (nav-apps, gids-hond…)?
3. Welke globale kenmerken moet het gebruiksconcept hebben om als comfortabel, betrouwbaar en niet-storend ervaren te worden (bv. manier van route starten, bestemming kiezen..)?

## 4. Methode Respondenten

5 interviews met ervaren gebruikers van een lange witte stok (blind/slechtziend),

Pseudoniem | Respondenttype | Datum | Locatie
Rory | Zeer slecht ziend, heeft een blindegeleidehond | 15/11/2025 | Licht en liefde gent
Mario | Blind geworden op +-30jarige leeftijd, heeft een blindegeleidehond | 15/11/2025 | Licht en liefde gent
Balliemedewerker Licht en liefde | Blind sinds geboorte | 17/11/2025 | Licht en liefde gent
Peter | Blind en doof | 18/11/2025 | Waregem
Herman | Voorzitter licht en liefde Sinds 18 jaar blind | 25/11/2025 | Licht en liefde gent

## 5. Prototypes

### 5.1. Haptische prototypes

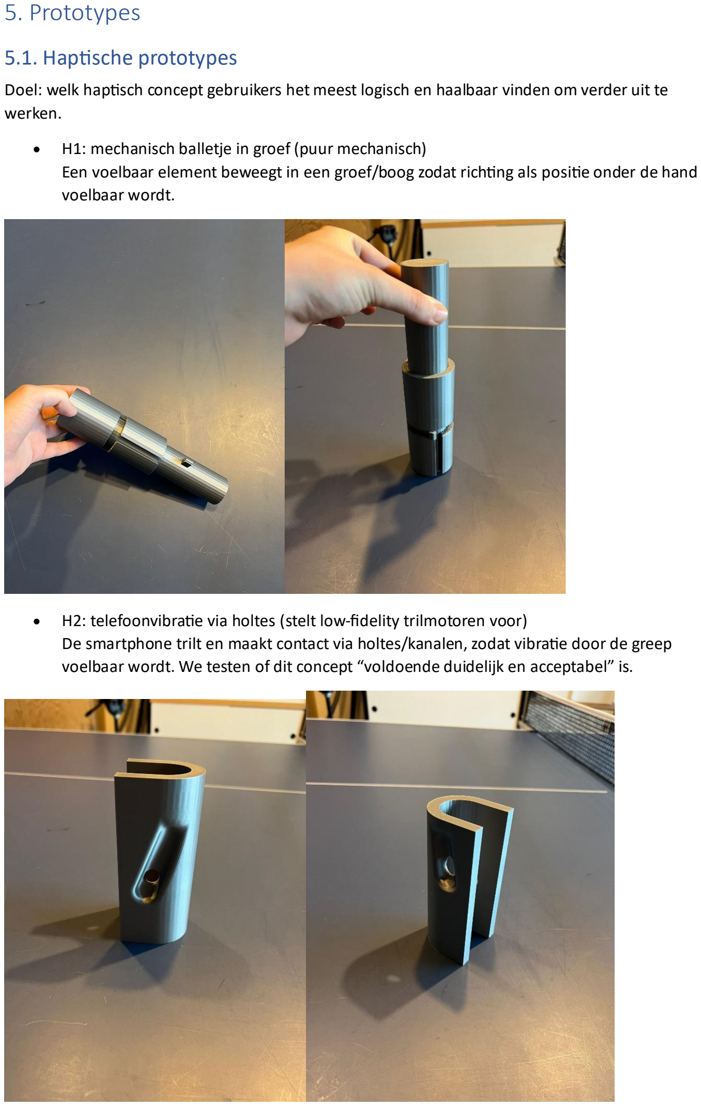
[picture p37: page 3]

Doel: welk haptisch concept gebruikers het meest logisch en haalbaar vinden om verder uit te werken.

- H1: mechanisch balletje in groef (puur mechanisch)
Een voelbaar element beweegt in een groef/boog zodat richting als positie onder de hand voelbaar wordt.
- H2: telefoonvibratie via holtes (stelt low-fidelity trilmotoren voor)
De smartphone trilt en maakt contact via holtes/kanalen, zodat vibratie door de greep voelbaar wordt. We testen of dit concept “voldoende duidelijk en acceptabel” is.

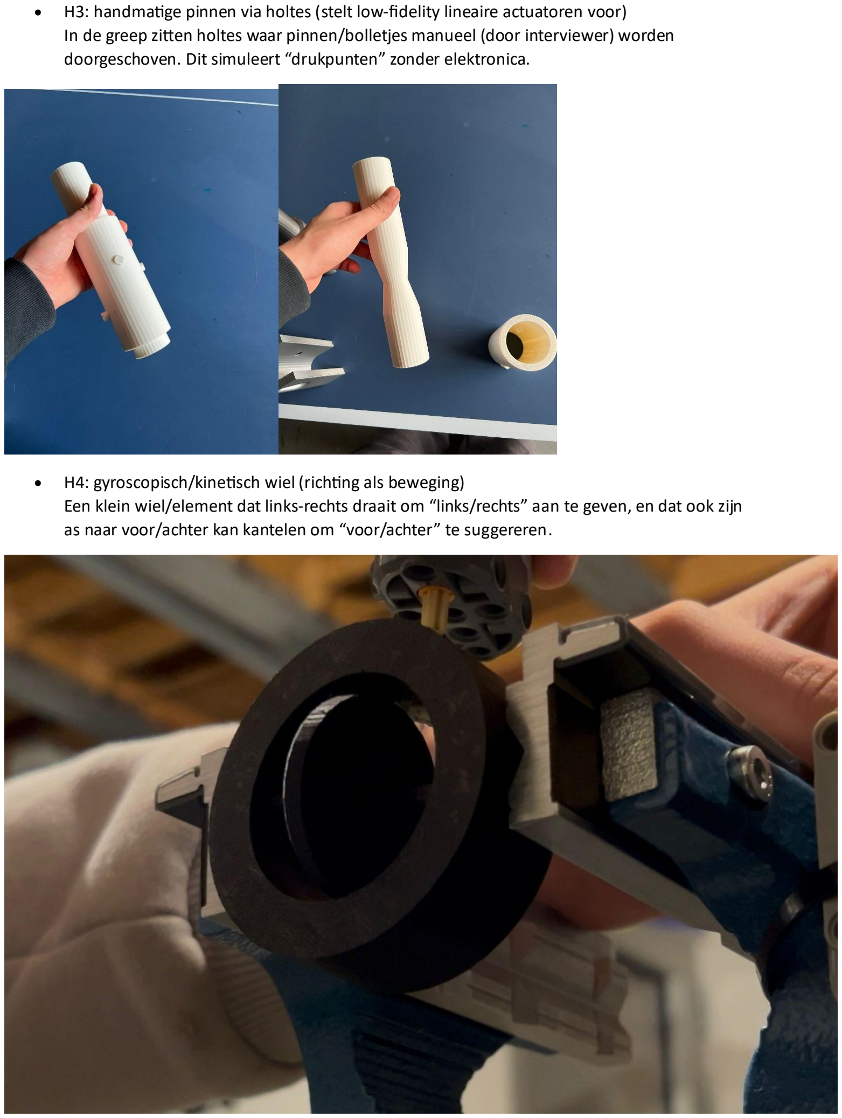
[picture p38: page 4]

- H3: handmatige pinnen via holtes (stelt low-fidelity lineaire actuatoren voor)
In de greep zitten holtes waar pinnen/bolletjes manueel (door interviewer) worden doorgeschoven. Dit simuleert “drukpunten” zonder elektronica.
- H4: gyroscopisch/kinetisch wiel (richting als beweging)
Een klein wiel/element dat links-rechts draait om “links/rechts” aan te geven, en dat ook zijn as naar voor/achter kan kantelen om “voor/achter” te suggereren.

- H5: Braille-handvat met pinnen (tactiele codering)
Een handvat waarop braille-achtige pinnen (vast of handmatig instelbaar) verschillende patronen vormen. Deze patronen coderen richting of informatie en maken het mogelijk om via tast herkenbare signalen te geven zonder visuele of auditieve feedback.

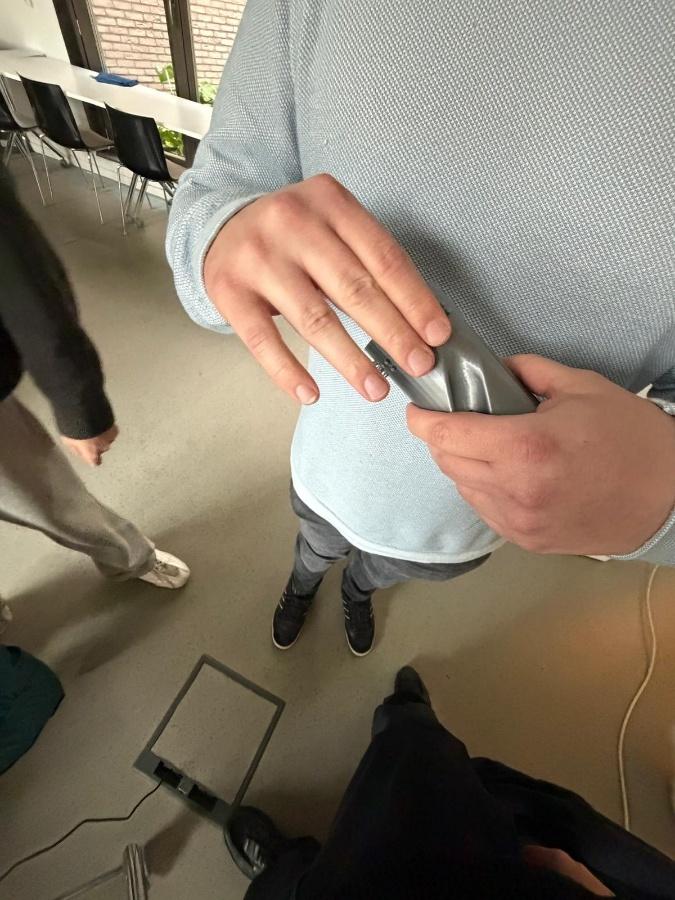
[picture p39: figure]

In Wave 1 worden deze haptische concepten handmatig bedient, zolang de gebruiker het gevoel kan ervaren.

### 5.2 Conceptprototypes (journey-matrix)

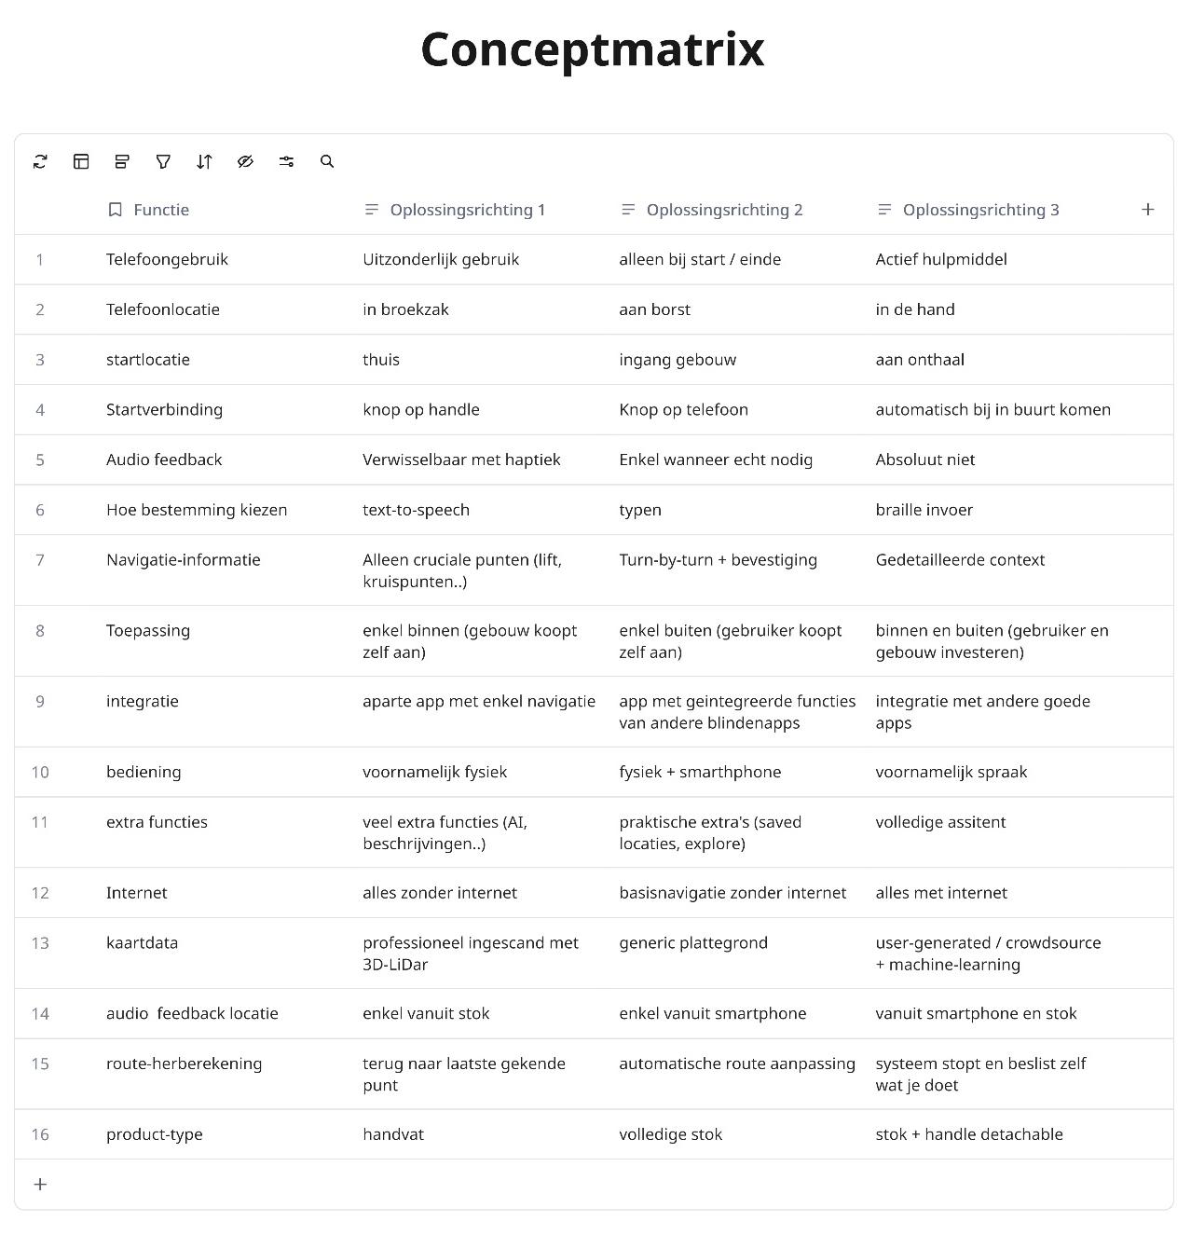
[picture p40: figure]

## 6. Voorbereiding

Meenemen

- 5 haptische prototypes (H1–H5)
- Conceptmatrix op telefoon/ papier
- Opnameapparatuur (smartphone/voice-recorder)

## 7. OVERZICHT & STRUCTUUR PROTOCOL

Totale duur per deelnemer: ± 45–60 minuten

- DEEL 1: Kwalificatie – Inleiding & voorstelling geïnterviewde (10’)
- DEEL 2: Confrontatie en appreciatie – Noden en verwachtingen (15’)

- DEEL 3: Conceptmatrix – Think aloud protocol (± 20’)
- DEEL 4: Simulatie – Simulatie van de oplossing (unguided) (10’)
- DEEL 5: Reflectie en conclusie – Evaluatie en acceptatie (15’)

Bijlage: Conceptmatrix SensePath

## 8. DISCUSSIEGIDS

## DEEL 1 – Kwalificatie

### Inleiding & voorstelling geïnterviewde (10’)

VOORAF

- Informed consent laten ondertekenen
- Eventuele audio-opname starten

Introductie interviewer

Ik wil u eerst en vooral bedanken om de tijd te nemen om vandaag deel te nemen aan dit onderzoek. Ik ga u vandaag een concept voorstellen waar we nog volop aan werken. Het gaat om een vroege test van een idee, geen afgewerkt product.

Het doel van dit gesprek is om beter te begrijpen hoe u zich vandaag verplaatst, welke moeilijkheden of stressmomenten u daarbij ervaart, en hoe een nieuw hulpmiddel u daarbij eventueel zou kunnen ondersteunen.

Belangrijk om te vermelden:

- Er zijn geen juiste of foute antwoorden
- We testen het concept, niet u

Voorstelling deelnemer
[@interviewer: hou dit deel informeel en geruststellend]
- Kunt u iets over uzelf vertellen?
- Hoe verplaatst u zich doorgaans buitenshuis?
- In welke contexten bent u het vaakst onderweg? (bv. openbaar vervoer, ziekenhuizen, winkels)
- Gebruikt u vandaag hulpmiddelen tijdens het navigeren? Welke?
- Gebruikt u soms een smartphone tijdens het verplaatsen? Wanneer wel en wanneer niet?

## DEEL 2 – Confrontatie en appreciatie

### Noden en verwachtingen (15’)

### 2.1 Eerste reactie op conceptomschrijving (± 7’)

[@interviewer: geef een korte, neutrale uitleg – nog geen prototypes tonen]

“SensePath is een concept waarbij een slimme handgreep op een witte stok samenwerkt met een smartphone-app om gebruikers te begeleiden tijdens het navigeren in gebouwen. Het systeem wil ondersteuning bieden bij oriëntatie, richting en beslissingsmomenten, zonder de gebruiker te overladen of de eigen vaardigheden te vervangen.”

Vragen

- “Wat is uw eerste reactie op dit idee?”
- “Wat vindt u er spontaan goed aan?”
- “Wat vindt u minder goed, of waar heeft u meteen vragen bij?”
- “Wat zou u hopen dat zo’n systeem voor u kan oplossen dat vandaag nog moeilijk is?”
- “In welke situaties ziet u zichzelf dit gebruiken?”
- “Zijn er situaties waarin u dit liever niet zou gebruiken? Waarom?”

[@interviewer: noteer verwachtingen, bezorgdheden en aannames]

### 2.2 Eerste reactie op prototypes (± 8’)

[@interviewer: toon de verschillende haptische prototypes, zonder uitleg of interactie]

Vragen

- “Als u deze verschillende handgrepen ziet, wat is uw eerste indruk?”
- “Welke spreekt u op het eerste zicht het meest aan? Waarom?”
- “Welke roept twijfel of weerstand op?”
- “Wat verwacht u dat deze handgrepen concreet zouden doen tijdens het stappen?”
- “Ziet u hier iets dat u meteen zou vertrouwen? Of net niet?”

[@interviewer: nog geen uitleg geven over werking of betekenis]

## DEEL 3 – Conceptmatrix

### Think aloud protocol (± 20’)

Algemeen

- De conceptmatrix wordt rij per rij besproken
- De deelnemer denkt luidop tijdens het maken van keuzes
- Er is geen juiste keuze
- De matrix zelf wordt niet geïnterpreteerd of gestuurd door de interviewer

[@interviewer: leg kort het think-aloud principe uit]

“Ik ga u per onderdeel enkele mogelijke oplossingen tonen. Ik wil u vragen om luidop te zeggen wat u denkt terwijl u kiest, ook als u twijfelt.”

Per functie (rij in de conceptmatrix)

1. Uitleg
- Leg de drie oplossingsrichtingen kort en neutraal uit.
2. Keuze
- “Welke van deze drie opties past het best bij hoe u SensePath zou willen gebruiken?”
3. Think aloud – motivatie
- “Waarom kiest u deze optie?”
- “Wat vindt u moeilijk of minder goed aan de andere opties?”
- “Wat zou voor u echt niet werken?”

[@interviewer: doorvragen op twijfel, onzekerheid en mentale modellen]

Selectieve verdiepingsvragen

- Telefoongebruik:
“Hoe voelt het idee dat de telefoon voortdurend nodig is?”
- Startlocatie:
“Wanneer heeft u het meest nood aan begeleiding?”
- Bediening:
“Hoeveel handelingen zijn nog aanvaardbaar?”
- Internet:
“Wat verwacht u dat het systeem nog doet zonder internet?”

## DEEL 4 – Simulatie

### Simulatie van de oplossing (guided) (10’)

Algemeen

- Alle haptische prototypes (H1–H5) komen aan bod
- Volgorde randomiseren per deelnemer
- Prototypes worden manueel bediend (Wizard-of-Oz)
- Focus op begrijpbaarheid, comfort en verstoring van normaal stokgebruik

Spontane interactie met haptische prototypes

[@interviewer: minimale sturing]

“U mag elk prototype even vasthouden en ervaren. Volg uw gevoel en probeer luidop te zeggen wat u denkt en voelt.”

Per prototype (H1–H5)

### 1. Verwachting (± 1’)

- “Wat verwacht u dat dit gaat doen?”

- “Wat lijkt u hier goed aan?”
- “Wat lijkt u lastig of onduidelijk?”

### 2. Interpretatie in stilstand (± 3’)

[@interviewer: geef 6–8 signalen of richtingen in willekeurige volgorde]

Na elk signaal:

- “Wat denkt u dat dit betekent?”
- “Hoe zeker bent u daarvan?” (0–10)

[@interviewer: noteer]

- correct / incorrect
- verwarring
- spontane opmerkingen

### 3. Mini-simulatie (± 2’)

[@interviewer: korte oriëntatie-oefening, bv. ‘volg – stop – links – rechts’]

Focus op:

- Begrijpt de deelnemer dit zonder uitleg?
- Stoort dit het normale stokgebruik?
- Voelt dit natuurlijk of geforceerd aan?

### 4. Evaluatie per prototype (± 1’)

Schaalvragen (1–7):

- “Hoe duidelijk is dit concept?”
- “Hoe comfortabel of aanvaardbaar is dit?”
- “Zou u dit in het echt willen proberen?”

Open:

- “Wat moet hier beter voor dit bruikbaar is?”
- “In welke situaties zou dit wel werken?”
- “In welke situaties niet?”

Na alle prototypes

- Laat de deelnemer H1–H5 rangschikken op:
1. duidelijkheid
2. comfort
3. algemene voorkeur

Afsluitvraag

- “Als we maar één van deze concepten verder mogen uitwerken, welke kiest u en waarom?”

## DEEL 5 – Reflectie en conclusie

### Evaluatie en acceptatie (15’)

Algemene evaluatie

- “Wat is uw algemene indruk van SensePath?”
- “Wat vindt u er sterk aan?”
- “Wat vindt u problematisch of zwak?”
- “Wat zou u zelf aanpassen?”

Gebruik & acceptatie

- “Zou u dit in het dagelijks leven willen gebruiken?”
- “In welke situaties zeker wel?”
- “In welke situaties liever niet?”
- “Wat zou u kunnen tegenhouden om dit te gebruiken?”
- prijs
- vertrouwen
- zichtbaarheid
- complexiteit
- “Hoeveel extra moeite (opladen, verbinden, app openen) is nog aanvaardbaar?”

Afsluitende vragen

- “Welke eigenschappen zijn voor u absoluut noodzakelijk?”
- “Is er iets aan dit concept dat u zeker niet wilt?”
- “Mist u nog iets dat vandaag niet aan bod kwam?”

AFSLUIT

- Deelnemer bedanken
- Vragen of foto’s van deelnemer + prototype mogen genomen worden voor rapportage

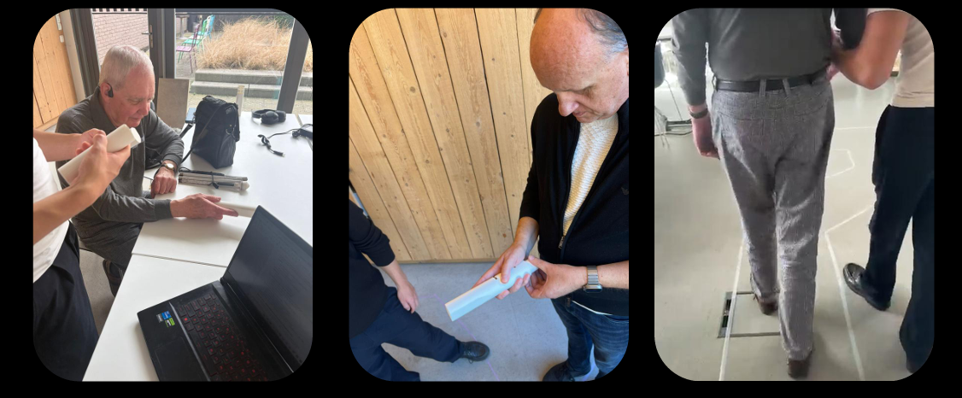
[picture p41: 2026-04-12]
img/test_sessions_dev2.png

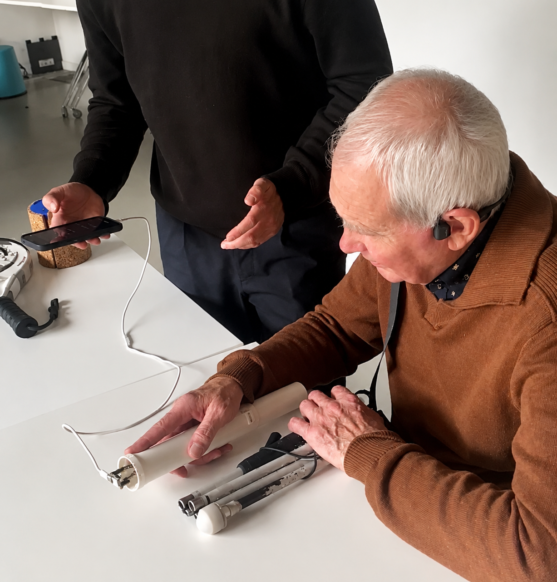
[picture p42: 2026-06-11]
img/test-opstelling-dev3.png

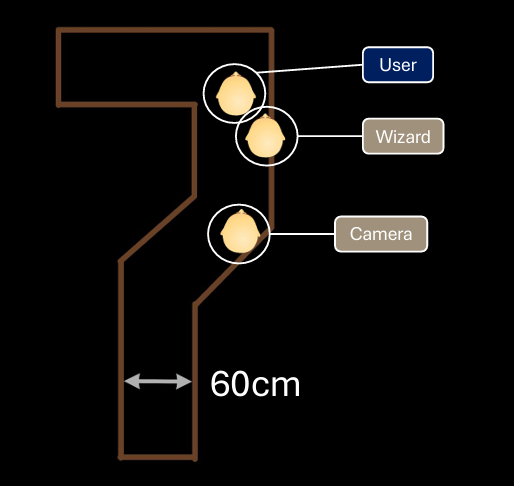
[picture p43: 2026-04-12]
img/path_test_3_dev2.png

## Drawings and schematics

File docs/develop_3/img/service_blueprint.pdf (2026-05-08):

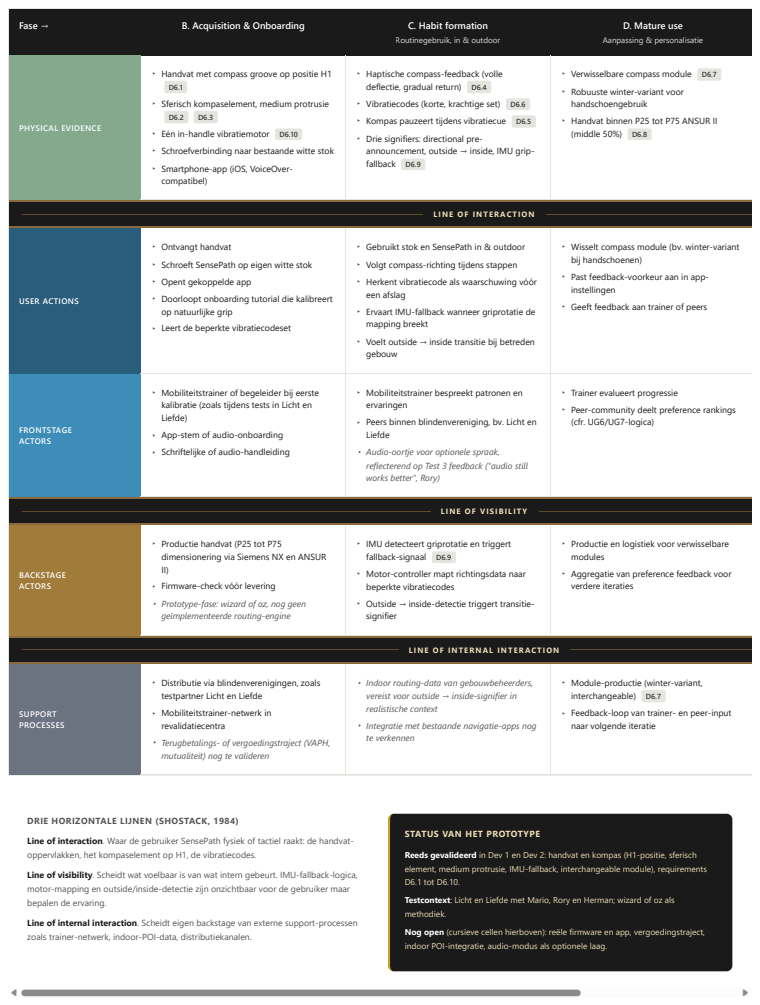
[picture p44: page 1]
Fase →; B. Acquisition & Onboarding; C. Habit formation; D. Mature use; PHYSICAL EVIDENCE; USER ACTIONS; FRONTSTAGE ACTORS; BACKSTAGE ACTORS; SUPPORT PROCESSES; Routinegebruik, in & outdoor; Aanpassing & personalisatie

Handvat met compass groove op positie H1
Sferisch kompaselement, medium protrusie
▸ Eén in-handle vibratiemotor D6.10
▸ Schroefverbinding naar bestaande witte stok
Smartphone-app (iOS, VoiceOver-
compatibel)

Haptische compass-feedback (volle
deflectie, gradual return) D6.4
▸ Vibratiecodes (korte, krachtige set) D6.6
▸ Kompas pauzeert tijdens vibratiecue D6.5
Drie signifiers: directional pre-
announcement, outside → inside, IMU grip-
fallback D6.9

▸ Verwisselbare compass module D6.7
Robuuste winter-variant voor
handschoengebruik
Handvat binnen P25 tot P75 ANSUR II
(middle 50%) D6.8

L INE OF INTER ACTION

▸ Ontvangt handvat
▸ Schroeft SensePath op eigen witte stok
▸ Opent gekoppelde app
Doorloopt onboarding tutorial die kalibreert
op natuurlijke grip
▸ Leert de beperkte vibratiecodeset

▸ Gebruikt stok en SensePath in & outdoor
▸ Volgt compass-richting tijdens stappen
Herkent vibratiecode als waarschuwing vóór
een afslag
Ervaart IMU-fallback wanneer griprotatie de
mapping breekt
Voelt outside → inside transitie bij betreden
gebouw

Wisselt compass module (bv. winter-variant
bij handschoenen)
Past feedback-voorkeur aan in app-
instellingen
▸ Geeft feedback aan trainer of peers

Mobiliteitstrainer of begeleider bij eerste
kalibratie (zoals tijdens tests in Licht en
Liefde)
▸ App-stem of audio-onboarding
▸ Schriftelijke of audio-handleiding

Mobiliteitstrainer bespreekt patronen en
ervaringen
Peers binnen blindenvereniging, bv. Licht en
Liefde
Audio-oortje voor optionele spraak,
reflecterend op Test 3 feedback ("audio still
works better", Rory)

▸ Trainer evalueert progressie
Peer-community deelt preference rankings
(cfr. UG6/UG7-logica)

L INE OF VI S IBI L IT Y

Productie handvat (P25 tot P75
dimensionering via Siemens NX en ANSUR
▸ Firmware-check vóór levering
Prototype-fase: wizard of oz, nog geen
geïmplementeerde routing-engine

IMU detecteert griprotatie en triggert
fallback-signaal D6.9
Motor-controller mapt richtingsdata naar
beperkte vibratiecodes
Outside → inside-detectie triggert transitie-
signifier

Productie en logistiek voor verwisselbare
modules
Aggregatie van preference feedback voor
verdere iteraties

L INE OF INTERNAL INTER ACTION

Distributie via blindenverenigingen, zoals
testpartner Licht en Liefde
Mobiliteitstrainer-netwerk in
revalidatiecentra
Terugbetalings- of vergoedingstraject (VAPH,
mutualiteit) nog te valideren

Indoor routing-data van gebouwbeheerders,
vereist voor outside → inside-signifier in
realistische context
Integratie met bestaande navigatie-apps nog
te verkennen

Module-productie (winter-variant,
interchangeable) D6.7
Feedback-loop van trainer- en peer-input
naar volgende iteratie

DRIE HORIZONTALE LIJNEN (SHOSTACK, 1984)
Line of interaction. Waar de gebruiker SensePath fysiek of tactiel raakt: de handvat-
oppervlakken, het kompaselement op H1, de vibratiecodes.
Line of visibility. Scheidt wat voelbaar is van wat intern gebeurt. IMU-fallback-logica,
motor-mapping en outside/inside-detectie zijn onzichtbaar voor de gebruiker maar
bepalen de ervaring.
Line of internal interaction. Scheidt eigen backstage van externe support-processen
zoals trainer-netwerk, indoor-POI-data, distributiekanalen.

STATUS VAN HET PROTOTYPE
Reeds gevalideerd in Dev 1 en Dev 2: handvat en kompas (H1-positie, sferisch
element, medium protrusie, IMU-fallback, interchangeable module), requirements
D6.1 tot D6.10.
Testcontext: Licht en Liefde met Mario, Rory en Herman; wizard of oz als
methodiek.
Nog open (cursieve cellen hierboven): reële firmware en app, vergoedingstraject,
indoor POI-integratie, audio-modus als optionele laag.

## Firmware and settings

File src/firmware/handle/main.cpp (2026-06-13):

// ═══════════════════════════════════════════════════════
// SensePath — HANDVAT bring-up firmware (XIAO ESP32-S3)
//
// Doel van deze build:
//   1. ESP-NOW ontvanger → de servo (mechanisch kompas) volgt de encoder
//      van de controller-module draadloos.
//   2. Serieel testmenu → elk component los valideren/finetunen.
//
// Nog NIET de volledige eindfirmware (geen deep-sleep, geen volledige
// haptiek-engine). Wel de eerste integratiestap: de draadloze link.
//
// Pinout (uit docs/wiring.md, XIAO ESP32-S3):
//   I2C SDA   D4  GPIO5   → DRV2605L SDA
//   I2C SCL   D5  GPIO6   → DRV2605L SCL
//   Knop      D3  GPIO4   → HOTUT (interne pull-up, naar GND)
//   Servo PWM D9  GPIO8   → MG90S signaal
//   Audio SD  D10 GPIO9   → MAX98357A SD-gate (+ 100k pull-down)
//   I2S BCLK  D6  GPIO43 / LRC D7 GPIO44 / DIN D8 GPIO7  (audio, later)
// ═══════════════════════════════════════════════════════

#include <Arduino.h>
#include <Wire.h>
#include <WiFi.h>
#include <esp_now.h>
#include <esp_wifi.h>
#include <ESPmDNS.h>
#include <Preferences.h>   // NVS-opslag voor app-instellingen
#include <Adafruit_DRV2605.h>
#include <ESP32Servo.h>
#include "driver/i2s.h"
#include "driver/rtc_io.h"
#include "esp_sleep.h"

#include <WebServer.h>   // softAP-webserver voor de telefoon-app (digital twin)
#include "protocol.h"   // gedeeld ESP-NOW packet-formaat (shared/protocol.h)
#include "audio_clips.h" // ingebedde spraak-clips (gegenereerd uit WAV)
#include "webapp.h"      // de hele telefoon-app als PROGMEM-string (INDEX_HTML)
#include "secrets.h"     // GOOGLE_MAPS_API_KEY (lokaal bestand, gitignored)

// ─── Pin-constanten (GPIO-nummers, zie wiring.md) ────────
constexpr uint8_t PIN_I2C_SDA  = 5;   // D4
constexpr uint8_t PIN_I2C_SCL  = 6;   // D5
constexpr uint8_t PIN_BUTTON   = 4;   // D3  (RTC-GPIO, later wake-pin)
constexpr uint8_t PIN_SERVO    = 8;   // D9
constexpr uint8_t PIN_AUDIO_SD = 9;   // D10 (MAX98357A shutdown-gate)
constexpr int     PIN_I2S_BCLK = 43;  // D6  → MAX98357A BCLK
constexpr int     PIN_I2S_LRC  = 44;  // D7  → MAX98357A LRC
constexpr int     PIN_I2S_DIN  = 7;   // D8  → MAX98357A DIN

// ─── Globale objecten ────────────────────────────────────
Adafruit_DRV2605 drv;
Servo compassServo;
WebServer server(80);          // serveert de app + /api/servo (digital twin)
Preferences prefs;             // NVS-opslag voor de app-instellingen

// ── App-instellingen (gesynced met webapp.h, persistent in NVS) ──────────
// Defaults zijn zo gekozen dat ze het HUIDIGE handvat-gedrag behouden:
// korte druk = ETA-clip, dubbel = locatie-clip, sterkte = Medium (= nu).
struct Settings {
    int btn_short     = 7;    // 7 = Spreek ETA op handvat   (= huidig gedrag)
    int btn_double    = 8;    // 8 = Spreek locatie op handvat (= huidig gedrag)
    int btn_long      = 0;    // 0 = Niets
    int vib_intensity = 1;    // 0=Laag 1=Medium(huidige sterkte) 2=Hoog
    int vib_m4         = 47;  // effect bij obstakel        (DRV ROM-id, preview)
    int vib_m6         = 12;  // effect bij koersafwijking
    int vib_turn_right = 1;   // afslag rechts (1x klik) → turn-pattern id
    int vib_turn_left  = 2;   // afslag links  (2x klik) → turn-pattern id
    int audio_enabled = 1;    // handvat-audioclips aan/uit
    int tts_rate      = 10;   // spraaksnelheid (app-zijde, *10)
    String emergency  = "";   // noodcontact-nummer (app gebruikt het)
};
Settings cfg;
float  hapticFactor   = 1.0f; // sterkte-multiplier voor de haptiek-engine
String pendingCommand = "";   // stok→app commando (app polt GET /api/pending)
int    pendingClip    = 0;    // 0=geen, 1=ETA, 2=locatie (in loop afgespeeld)
int    lastClip       = 0;    // laatst gespeelde clip (voor "herhaal laatste")
bool drvFound = false;
bool servoAttached = false;

// ─── Knop-debounce / press-classificatie (bring-up versie) ─
int lastButtonState = HIGH;
uint32_t buttonChangedAt = 0;
uint32_t buttonPressedAt = 0;

// ─── Servo: veilig aansturen ─────────────────────────────
// DRIE onafhankelijke beveiligingen zodat de servo NOOIT kan blijven
// blokkeren (de oorzaak van de oververhitting):
//   1. AUTO-DETACH: zodra de servo stilstaat, gaat het PWM-signaal uit →
//      geen koppel = geen stall-stroom = geen warmte.
//   2. WATCHDOG: de servo wordt nooit langer dan SERVO_MAX_ENERGIZED_MS
//      onafgebroken aangestuurd, wat er ook gebeurt (vangt elke bug).
//   3. JOG-KALIBRATIE: kalibreren gebeurt in kleine stapjes, niet door
//      continu tegen een wand te schuiven.
// Daarbovenop: slew-rate-limiting (nooit springen) + harde clamps.
// ── Gemeten servo-kalibratie (handvat-prototype, Develop 3) ──────────
//   onderrand (mechanische wand) : 1406 µs
//   bovenrand (mechanische wand) : 2106 µs
//   nulpunt (midden)             : 1756 µs   (totaal bereik ~700 µs)
// Het werkbereik ligt 14 µs binnen de wanden om wand-stall te vermijden.
// Deze waarden vormen de basis voor de latere encoder→servo mapping.
constexpr int SERVO_CENTER_US = 1756;     // nulpunt
constexpr int SERVO_MIN_US    = 1420;     // ~onderrand (14 µs marge)
constexpr int SERVO_MAX_US    = 2092;     // ~bovenrand (14 µs marge)

bool calMode = false;                     // kalibratie-modus actief?
int  calMarks = 0;                        // aantal gemarkeerde limieten (0/1/2)
int  calLimit1 = 0, calLimit2 = 0;        // gemeten uiterste posities
int  servoUs = SERVO_CENTER_US;           // huidige (gecommandeerde) pulsbreedte
int  servoTargetUs = SERVO_CENTER_US;     // doel waar we traag naartoe gaan
uint32_t lastServoStep = 0;
uint32_t servoAttachedAt = 0;             // moment van attach (voor watchdog)
constexpr int SERVO_BOOT_US = SERVO_CENTER_US;  // rust = nulpunt
constexpr int SERVO_STEP_US = 6;          // 6 µs per stap → ~servo-maximum = real-time volgen
constexpr uint32_t SERVO_STEP_MS = 1;     // elke 1 ms een stap
constexpr int SERVO_CLAMP_MIN = SERVO_MIN_US;   // kan fysiek niet voorbij de randen
constexpr int SERVO_CLAMP_MAX = SERVO_MAX_US;
constexpr int JOG_STEP_US = 25;           // verplaatsing per jog-druk ('[' / ']')
constexpr uint32_t SERVO_IDLE_DETACH_MS = 700;      // stil → loskoppelen (veilig)
constexpr uint32_t SERVO_MAX_ENERGIZED_MS = 10000;  // backstop; idle-detach is de hoofdbeveiliging
bool servoIdle = false;
uint32_t servoReachedAt = 0;

// ─── Motor aan/uit-toestand (toggle met de HOTUT-knop) ───
bool motorOn = false;

void setMotor(bool on) {
    motorOn = on;
    if (!drvFound) { Serial.println("  MOTOR: DRV niet gevonden!"); return; }
    drv.setMode(DRV2605_MODE_REALTIME);   // directe analoge drive
    drv.setRealtimeValue(on ? 127 : 0);   // 127 = volle kracht
    Serial.printf("  MOTOR: %s\n", on ? "AAN (vol)" : "UIT");
}

// ═════════════════════════════════════════════════════════
//  Haptiek pattern-engine (non-blocking, segment-gebaseerd)
//  Geport uit de oude firmware: speelt trilpatronen via RTP op de
//  DRV2605L. Elke cue start een patroon; updateHaptics() stapt erdoor.
// ═════════════════════════════════════════════════════════
struct Segment { uint32_t durationMs; uint8_t targetPercent; bool ramp; };
constexpr uint8_t MAX_SEGMENTS = 32;

struct PatternState {
    Segment  segments[MAX_SEGMENTS];
    uint8_t  count = 0, index = 0;
    bool     active = false, loop = false;
    uint32_t segStartedAt = 0;
    uint8_t  segStartPercent = 0, outputPercent = 0;
    const char* name = "idle";
};
PatternState pat;
uint8_t lastRtp = 255;
uint32_t cueDispatchCount = 0;            // diagnose: aantal afgespeelde cues
uint8_t  patMaxRtp = 0;                   // diagnose: hoogste RTP tijdens patroon
uint32_t patWrites = 0;                   // diagnose: aantal motor-schrijfacties

uint8_t clampPct(int v) { return v < 0 ? 0 : (v > 100 ? 100 : (uint8_t)v); }
uint8_t pctToRtp(uint8_t p) { return map(clampPct(p), 0, 100, 0, 127); }

void hapticWrite(uint8_t pct) {
    pat.outputPercent = clampPct(pct);
    if (!drvFound) return;
    // Sterkte-instelling (Laag/Medium/Hoog) schaalt elke haptiek-uitgang.
    uint8_t scaled = clampPct((int)(pat.outputPercent * hapticFactor + 0.5f));
    uint8_t rtp = pctToRtp(scaled);
    if (rtp == lastRtp) return;
    drv.setRealtimeValue(rtp);
    lastRtp = rtp;
    if (rtp > patMaxRtp) patMaxRtp = rtp;
    patWrites++;
}

void hapticStop() {
    if (patWrites > 0)
        Serial.printf("  patroon klaar: maxRtp=%u writes=%lu\n", patMaxRtp, (unsigned long)patWrites);
    pat.active = false; pat.loop = false; pat.count = 0; pat.index = 0;
    pat.name = "idle"; pat.segStartPercent = 0;
    hapticWrite(0);
}

void hapticAddSeg(uint32_t ms, uint8_t pct, bool ramp = false) {
    if (pat.count >= MAX_SEGMENTS) return;
    pat.segments[pat.count++] = {ms, clampPct(pct), ramp};
}

void hapticClear() { pat.count = 0; pat.index = 0; pat.segStartPercent = pat.outputPercent; }

void hapticBegin(const char* name, bool loop = false) {
    pat.name = name; pat.loop = loop; pat.index = 0;
    pat.active = pat.count > 0;
    pat.segStartedAt = millis(); pat.segStartPercent = pat.outputPercent;
    motorOn = false;                              // engine neemt de motor over
    lastRtp = 255;                                // forceer verse motor-schrijf
    patMaxRtp = 0; patWrites = 0;                 // diagnose-tellers resetten
    if (drvFound) drv.setMode(DRV2605_MODE_REALTIME);
    if (!pat.active) hapticStop();
    Serial.printf("  HAPTIEK: %s\n", name);
}

// Eén puls met fade-in, daarna optioneel een stilte (offMs).
void hapticPulse(uint16_t onMs, uint8_t pct, uint32_t offMs = 0, uint16_t fadeInMs = 80) {
    uint32_t hold = onMs > fadeInMs ? onMs - fadeInMs : 0;
    hapticAddSeg(fadeInMs, pct, true);
    if (hold > 0) hapticAddSeg(hold, pct, false);
    hapticAddSeg(20, 0, false);
    if (offMs > 0) hapticAddSeg(offMs, 0, false);
}

void updateHaptics() {
    if (!pat.active || pat.count == 0) return;
    uint32_t now = millis();
    Segment& s = pat.segments[pat.index];
    uint32_t elapsed = now - pat.segStartedAt;

    if (elapsed >= s.durationMs) {
        hapticWrite(s.targetPercent);
        pat.index++;
        if (pat.index >= pat.count) {
            if (pat.loop) pat.index = 0;
            else { hapticStop(); return; }
        }
        pat.segStartedAt = now; pat.segStartPercent = pat.outputPercent;
        return;
    }
    if (s.ramp && s.durationMs > 0) {
        int delta = (int)s.targetPercent - (int)pat.segStartPercent;
        uint8_t v = pat.segStartPercent + (delta * (int)elapsed) / (int)s.durationMs;
        hapticWrite(v);
    } else {
        hapticWrite(s.targetPercent);
    }
}

// Speelt een INSTELBAAR afslag-trilpatroon (id uit TURN_PATTERNS in webapp.h;
// cfg.vib_turn_right / cfg.vib_turn_left bepalen welk patroon per richting).
// Coin-ERM voelt alleen lange pulsen, dus elk patroon bestaat uit pulsen van
// >=350 ms op vol vermogen (geschaald door de sterkte-instelling).
void playTurnPattern(int id) {
    hapticClear();
    constexpr uint16_t SHORT_MS = 350, GAP_MS = 200, LONG_MS = 600;
    switch (id) {
        case 2:  hapticPulse(SHORT_MS, 100, GAP_MS, 40);                      // 2 trillingen
                 hapticPulse(SHORT_MS, 100, 0, 40); break;
        case 3:  hapticPulse(SHORT_MS, 100, GAP_MS, 40);                      // 3 trillingen
                 hapticPulse(SHORT_MS, 100, GAP_MS, 40);
                 hapticPulse(SHORT_MS, 100, 0, 40); break;
        case 4:  hapticPulse(LONG_MS, 100, 0, 50); break;                     // 1 lange trilling
        case 5:  hapticPulse(SHORT_MS, 100, GAP_MS, 40);                      // kort dan lang
                 hapticPulse(LONG_MS, 100, 0, 50); break;
        default: hapticPulse(SHORT_MS, 100, 0, 40); break;                    // 1 trilling (id 1)
    }
    hapticBegin("afslag");
}

// Wake-bevestiging: 3 oplopende pulsen ("ta-ta-TAAA"), als een power-on.
// Bewust 3 pulsen → onderscheidt van de afslag-tikken (1 of 2) en de slaap-buzz.
void hapticWake() {
    hapticClear();
    hapticPulse(250, 100, 150, 40);
    hapticPulse(300, 100, 150, 40);
    hapticPulse(500, 100, 0,   40);
    hapticBegin("wake-bevestiging");
}

// Centrale cue → respons dispatcher (fase 2 vult de rest aan).
void dispatchCue(uint8_t cue) {
    cueDispatchCount++;
    Serial.printf("  CUE ontvangen: %u\n", cue);
    switch (cue) {
        case sensepath::CUE_TURN_RIGHT: playTurnPattern(cfg.vib_turn_right); break;
        case sensepath::CUE_TURN_LEFT:  playTurnPattern(cfg.vib_turn_left);  break;
        default: break;
    }
}

// ═════════════════════════════════════════════════════════
//  ESP-NOW link (ontvangt encoder-updates van de controller)
// ═════════════════════════════════════════════════════════
constexpr float US_PER_COUNT = 22.0f;     // servo-µs per encoder-detent (afstembaar)

volatile bool     linkRx = false;         // nieuw pakket ontvangen?
volatile int16_t  linkAbsolute = 0;       // laatst ontvangen encoder-positie
volatile uint8_t  linkButtons = 0;        // laatst ontvangen knop-bits (bit0 = recenter)
volatile uint8_t  linkCue = 0;            // laatst ontvangen cue-waarde
volatile uint8_t  linkCueId = 0;          // cue-event-id (verandert per nieuwe cue)
volatile uint32_t linkRxCount = 0;        // diagnose: aantal ontvangen pakketten
int16_t  encoderOffset = 0;               // encoder-stand die als "midden" geldt
uint32_t linkLastRxMs = 0;                // tijdstip laatste pakket (link-loss later)

// ESP-NOW receive-callback (core 2.x signatuur). Houdt het kort: alleen data
// opslaan, het echte werk gebeurt in serviceLink() in de hoofdlus.
void onEspNowRecv(const uint8_t* mac, const uint8_t* data, int len) {
    if (len < (int)sizeof(sensepath::EncoderUpdate)) return;
    const sensepath::EncoderUpdate* u = (const sensepath::EncoderUpdate*)data;
    if (u->version != sensepath::PROTOCOL_VERSION) return;
    linkAbsolute = u->absolute;
    linkButtons = u->buttons;
    linkCue = u->cue;
    linkCueId = u->cueId;
    linkRxCount++;
    linkRx = true;
}

// Verbindt met de telefoon-hotspot (STA) zodat de telefoon internet heeft voor
// Google Maps op hetzelfde netwerk. ESP-NOW volgt automatisch het hotspot-kanaal,
// dus de controller (die ook de hotspot joint) blijft bereikbaar. Lukt de
// hotspot niet, dan valt het handvat terug op een eigen AP op kanaal 1 (de twin
// werkt dan nog, zonder internet); de controller valt dan ook terug op kanaal 1.
bool wifiOnHotspot = false;

// WiFi-presets uit secrets.h, in volgorde van voorkeur geprobeerd.
struct WifiPreset { const char* ssid; const char* pass; };
static WifiPreset WIFI_NETS[] = WIFI_PRESETS;
static const int  WIFI_N = sizeof(WIFI_NETS) / sizeof(WIFI_NETS[0]);

void setupNetwork() {
    WiFi.persistent(false);
    WiFi.mode(WIFI_STA);

    // Probeer elke preset (max 10 s) tot er één verbindt.
    for (int i = 0; i < WIFI_N && WiFi.status() != WL_CONNECTED; i++) {
        Serial.printf("WiFi proberen: '%s' ", WIFI_NETS[i].ssid);
        WiFi.begin(WIFI_NETS[i].ssid, WIFI_NETS[i].pass);
        uint32_t t0 = millis();
        while (WiFi.status() != WL_CONNECTED && millis() - t0 < 10000) { delay(300); Serial.print("."); }
        Serial.println();
        if (WiFi.status() != WL_CONNECTED) WiFi.disconnect();
    }

    if (WiFi.status() == WL_CONNECTED) {
        wifiOnHotspot = true;
        Serial.printf(">>> Verbonden met '%s'. Handvat-IP: ", WiFi.SSID().c_str());
        Serial.println(WiFi.localIP());
        Serial.printf(">>> WiFi-kanaal %d (ESP-NOW volgt dit kanaal)\n", WiFi.channel());
        if (MDNS.begin("sensepath")) {
            MDNS.addService("http", "tcp", 80);
            Serial.println(">>> Bereikbaar op http://sensepath.local/  (of het IP hierboven)");
        }
    } else {
        Serial.println(">>> Hotspot niet gevonden → eigen AP 'SensePath' op kanaal 1 (geen internet)");
        WiFi.mode(WIFI_AP_STA);
        WiFi.softAP("SensePath", "sensepath123", sensepath::ESPNOW_CHANNEL);
        Serial.println(">>> Bereikbaar op http://192.168.4.1/");
    }
    Serial.print(">>> Handvat STA-MAC (staat al in de controller): ");
    Serial.println(WiFi.macAddress());

    esp_wifi_set_ps(WIFI_PS_NONE);   // power-save uit → stabielere ESP-NOW naast WiFi
    if (esp_now_init() != ESP_OK) {
        Serial.println("FOUT: ESP-NOW init mislukt");
        return;
    }
    esp_now_register_recv_cb(onEspNowRecv);
    Serial.printf("ESP-NOW ontvanger actief op kanaal %d\n", WiFi.channel());
}

// ═════════════════════════════════════════════════════════
//  App-instellingen: NVS-opslag + toepassing op het handvat
//  De telefoon-app POST't instellingen naar /api/settings; ze worden hier
//  persistent bewaard (NVS) en meteen toegepast: sterkte → haptiek-multiplier,
//  knop-acties → executeAction, audio → clip-poort.
// ═════════════════════════════════════════════════════════
void applyIntensity() {
    // Coin-ERM zit bij Medium al op vol vermogen (geen marge erboven), dus
    // Hoog == Medium; Laag halveert ongeveer. Medium = de huidige sterkte.
    switch (cfg.vib_intensity) {
        case 0:  hapticFactor = 0.60f; break;  // Laag
        case 2:  hapticFactor = 1.00f; break;  // Hoog
        default: hapticFactor = 1.00f; break;  // Medium (= huidig gedrag)
    }
}

void loadSettings() {
    prefs.begin("sensepath", true);            // read-only
    cfg.btn_short     = prefs.getInt("btn_short",     cfg.btn_short);
    cfg.btn_double    = prefs.getInt("btn_double",    cfg.btn_double);
    cfg.btn_long      = prefs.getInt("btn_long",      cfg.btn_long);
    cfg.vib_intensity = prefs.getInt("vib_intensity", cfg.vib_intensity);
    cfg.vib_m4         = prefs.getInt("vib_m4",     cfg.vib_m4);
    cfg.vib_m6         = prefs.getInt("vib_m6",     cfg.vib_m6);
    cfg.vib_turn_right = prefs.getInt("vib_turn_r", cfg.vib_turn_right);
    cfg.vib_turn_left  = prefs.getInt("vib_turn_l", cfg.vib_turn_left);
    cfg.audio_enabled = prefs.getInt("audio_enabled", cfg.audio_enabled);
    cfg.tts_rate      = prefs.getInt("tts_rate",      cfg.tts_rate);
    cfg.emergency     = prefs.getString("emergency",  cfg.emergency);
    prefs.end();
    applyIntensity();
}

void storeSettings() {
    prefs.begin("sensepath", false);           // read-write
    prefs.putInt("btn_short",     cfg.btn_short);
    prefs.putInt("btn_double",    cfg.btn_double);
    prefs.putInt("btn_long",      cfg.btn_long);
    prefs.putInt("vib_intensity", cfg.vib_intensity);
    prefs.putInt("vib_m4",     cfg.vib_m4);
    prefs.putInt("vib_m6",     cfg.vib_m6);
    prefs.putInt("vib_turn_r", cfg.vib_turn_right);
    prefs.putInt("vib_turn_l", cfg.vib_turn_left);
    prefs.putInt("audio_enabled", cfg.audio_enabled);
    prefs.putInt("tts_rate",      cfg.tts_rate);
    prefs.putString("emergency",  cfg.emergency);
    prefs.end();
    applyIntensity();
}

// Speelt een DRV ROM-effect (voor de effect-preview vanuit de app).
void playRomEffect(uint8_t id) {
    if (!drvFound) return;
    hapticStop();                              // stop een eventueel lopend patroon
    drv.selectLibrary(1);
    drv.setMode(DRV2605_MODE_INTTRIG);
    drv.setWaveform(0, id);
    drv.setWaveform(1, 0);
    drv.go();
}

// Speelt een clip via de handvat-speaker (1=ETA, 2=locatie) en onthoudt hem
// voor "herhaal laatste". Respecteert de audio-instelling.
void speakClip(int clip) {
    if (!cfg.audio_enabled || clip <= 0) return;
    pendingClip = clip;
    lastClip = clip;
}

void enterDeepSleep();   // vooruit-declaratie (definitie verderop in het bestand)

// Voert een knop-ACTIE uit (ids gesynced met ACTIONS in webapp.h). ALLE
// spraak komt uit de HANDVAT-SPEAKER (clips), niet via de telefoon-TTS.
void executeAction(int id) {
    switch (id) {
        case 0:  break;                                              // Niets
        case 1:  speakClip(2); break;                                // Vraag locatie  → locatie-clip
        case 2:  speakClip(1); break;                                // Vraag route    → ETA-clip
        case 3:  speakClip(lastClip); break;                         // Herhaal laatste clip
        case 4:  hapticClear(); hapticPulse(250, 100, 0, 40);        // trilling-bevestiging
                 hapticBegin("knop-bevestiging"); break;
        case 5:  pendingCommand = "EMERGENCY";                       // noodhulp: telefoon belt op
                 hapticClear(); hapticPulse(400, 100, 0, 50);
                 hapticBegin("noodhulp"); break;
        case 6:  cfg.audio_enabled = !cfg.audio_enabled; storeSettings();  // audio aan/uit
                 hapticClear(); hapticPulse(150, 100, 0, 30);
                 hapticBegin("audio-toggle"); break;
        case 7:  speakClip(1); break;                                // ETA-clip op handvat
        case 8:  speakClip(2); break;                                // locatie-clip op handvat
        case 9:  enterDeepSleep(); break;                            // slaapstand (keert niet terug)
        default: break;
    }
    Serial.printf("  ACTIE uitgevoerd: id=%d\n", id);
}

// Minimale parser voor een platte JSON-body: "key":123  of  "key":"tekst".
static int jsonInt(const String& body, const char* key, int fallback) {
    String tag = String("\"") + key + "\"";
    int k = body.indexOf(tag);
    if (k < 0) return fallback;
    int c = body.indexOf(':', k + tag.length());
    if (c < 0) return fallback;
    return body.substring(c + 1).toInt();
}
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
void loop() {
    server.handleClient();   // telefoon-app serveren + twin-polling beantwoorden
    serviceLink();
    handleSerial();
    pollButton();
    serviceServo();
    updateHaptics();
    if (pendingClip == 1)      { pendingClip = 0; playClip(eta_pcm, eta_len, eta_rate); }
    else if (pendingClip == 2) { pendingClip = 0; playClip(locatie_pcm, locatie_len, locatie_rate); }
    delay(1);
}

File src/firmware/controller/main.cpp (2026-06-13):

// ═══════════════════════════════════════════════════════
// SensePath — CONTROLLER firmware (XIAO ESP32-C3)
//
// Wizard-of-Oz controller-module. Leest de KY-040 roterende encoder en
// stuurt de positie draadloos via ESP-NOW naar het handvat (ESP32-S3),
// dat op zijn beurt de servo (mechanisch kompas) aanstuurt.
//
// Pinout (uit docs/wiring.md, XIAO ESP32-C3 — gebruik de Dx-labels):
//   Encoder CLK (A)  D0  → KY-040 CLK   (interrupt)
//   Encoder DT  (B)  D1  → KY-040 DT
//   Encoder SW       D2  → KY-040 drukknop (interne pull-up)
//   Encoder +        3V3
//   Encoder GND      GND
// ═══════════════════════════════════════════════════════

#include <Arduino.h>
#include <WiFi.h>
#include <esp_now.h>
#include <esp_wifi.h>

#include "protocol.h"
#include "secrets.h"   // WIFI_SSID + WIFI_PASSWORD van de hotspot (lokaal, gitignored)

// ─── Pinnen (Dx-labels van het XIAO-C3 board) ────────────
// Servo-rotatie-encoder (de goede) op D3/D4/D5.
constexpr uint8_t PIN_ENC_CLK  = D3;
constexpr uint8_t PIN_ENC_DT   = D4;
constexpr uint8_t PIN_ENC_SW   = D5;
// Oude encoder: enkel zijn drukknop gebruiken voor de afslag-cues.
constexpr uint8_t PIN_CUE_SW   = D2;

// ─── Encoder-positie (robuuste quadrature-decoder) ───────
// Telt precies 1 stap per detent en negeert contact-bounce via een
// transitietabel: lrsum bereikt alleen ±4 na een volledige geldige
// klik-sequentie. Interrupt op BEIDE pinnen (CLK én DT), CHANGE.
volatile int32_t encPos = 0;
volatile uint8_t encMem = 3;
volatile int8_t  encSum = 0;
const int8_t ENC_TRANS[16] = {0, -1, 1, 0, 1, 0, 0, -1, -1, 0, 0, 1, 0, 1, -1, 0};

void IRAM_ATTR onEncoder() {
    encMem = ((encMem & 0x03) << 2) | (digitalRead(PIN_ENC_CLK) << 1) | digitalRead(PIN_ENC_DT);
    encSum += ENC_TRANS[encMem & 0x0f];
    if (encSum >= 4)      { encPos++; encSum = 0; }   // 1 detent met de klok mee
    else if (encSum <= -4){ encPos--; encSum = 0; }   // 1 detent tegen de klok in
}

// Gevoeligheid: elke encoder-detent telt ENC_SCALE keer mee → minder draaien
// nodig om de bol naar de rand te brengen (~90° i.p.v. ~275°).
constexpr int ENC_SCALE = 3;

// ─── Cue-state (afslag-waarschuwingen via oude encoder-knop) ─
uint8_t curCue = sensepath::CUE_NONE;
uint8_t cueId  = 0;                 // hoogt op bij elke nieuwe cue
uint32_t cueBtnTotalDbg = 0;        // diagnose: totaal aantal D2-drukken

void fireCue(uint8_t cue, const char* naam) {
    curCue = cue;
    cueId++;
    Serial.printf("CUE afgevuurd: %s (id=%u)\n", naam, cueId);
}

// ─── ESP-NOW ─────────────────────────────────────────────
esp_now_peer_info_t peer = {};
uint8_t  seq = 0;
uint32_t lastSendMs = 0;
uint32_t sentOk = 0, sentFail = 0;

void onSent(const uint8_t* mac, esp_now_send_status_t status) {
    if (status == ESP_NOW_SEND_SUCCESS) sentOk++;
    else                                sentFail++;
}

// WiFi-presets uit secrets.h, in volgorde van voorkeur geprobeerd
// (identiek aan handle/secrets.h zodat beide op hetzelfde kanaal komen).
struct WifiPreset { const char* ssid; const char* pass; };
static WifiPreset WIFI_NETS[] = WIFI_PRESETS;
static const int  WIFI_N = sizeof(WIFI_NETS) / sizeof(WIFI_NETS[0]);

void setup() {
    Serial.begin(115200);
    delay(300);
    Serial.println();
    Serial.println("=== SensePath CONTROLLER (XIAO ESP32-C3) ===");

    pinMode(PIN_ENC_CLK, INPUT_PULLUP);
    pinMode(PIN_ENC_DT,  INPUT_PULLUP);
    pinMode(PIN_ENC_SW,  INPUT_PULLUP);
    pinMode(PIN_CUE_SW,  INPUT_PULLUP);
    attachInterrupt(digitalPinToInterrupt(PIN_ENC_CLK), onEncoder, CHANGE);
    attachInterrupt(digitalPinToInterrupt(PIN_ENC_DT),  onEncoder, CHANGE);

    // Join dezelfde hotspot als het handvat, zodat ESP-NOW automatisch op het
    // hotspot-kanaal zit. Lukt de hotspot niet, terugval op kanaal 1 (zoals het
    // handvat). De controller heeft GEEN webserver nodig; het joint de WiFi enkel
    // om op het juiste ESP-NOW-kanaal te komen.
    WiFi.mode(WIFI_STA);
    // Probeer elke preset (max 10 s) tot er één verbindt.
    for (int i = 0; i < WIFI_N && WiFi.status() != WL_CONNECTED; i++) {
        Serial.printf("WiFi proberen: '%s' ", WIFI_NETS[i].ssid);
        WiFi.begin(WIFI_NETS[i].ssid, WIFI_NETS[i].pass);
        uint32_t wt0 = millis();
        while (WiFi.status() != WL_CONNECTED && millis() - wt0 < 10000) { delay(300); Serial.print("."); }
        Serial.println();
        if (WiFi.status() != WL_CONNECTED) WiFi.disconnect();
    }
    if (WiFi.status() == WL_CONNECTED) {
        Serial.printf("Verbonden met '%s', kanaal %d (ESP-NOW volgt dit)\n",
                      WiFi.SSID().c_str(), WiFi.channel());
    } else {
        WiFi.disconnect();
        esp_wifi_set_channel(sensepath::ESPNOW_CHANNEL, WIFI_SECOND_CHAN_NONE);
        Serial.println("Geen netwerk gevonden -> ESP-NOW terugval op kanaal 1");
    }
    esp_wifi_set_ps(WIFI_PS_NONE);   // power-save uit -> stabielere ESP-NOW
    Serial.print("Controller MAC: ");
    Serial.println(WiFi.macAddress());

    if (esp_now_init() != ESP_OK) {
        Serial.println("FOUT: ESP-NOW init mislukt");
        return;
    }
    esp_now_register_send_cb(onSent);

    memcpy(peer.peer_addr, sensepath::HANDLE_MAC, 6);
    peer.channel = 0;   // 0 = huidig kanaal (volgt de hotspot, of de terugval op 1)
    peer.encrypt = false;
    if (esp_now_add_peer(&peer) != ESP_OK) {
        Serial.println("FOUT: peer (handvat) toevoegen mislukt");
        return;
    }
    Serial.printf("ESP-NOW zender klaar, kanaal %d. Draai de encoder.\n",
                  sensepath::ESPNOW_CHANNEL);
}
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

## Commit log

2026-05-08 Develop 3: UX & Service Design, CMF deepdive en finale user test
    - README: Develop 3 hoofdstuk toegevoegd met onderzoeksvragen, sample,
    prototype-uitleg, UX- en CMF-feedback, design implicaties, conclusies
    en kritische reflectie. Bijlagen-tabel uitgebreid met Develop links.
    - docs/develop_3.md: emotie-matrix, Norman lagen, microinteracties (M1 - M9),
    stakeholder map, customer journey, service blueprint.
    - docs/develop_3/: HTML- en PNG-versies van de drie service-design
    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
2026-05-09 README: em dashes in Develop 3 sectie vervangen
    Em dashes in mijn Develop 3 toevoegingen vervangen door punt of komma
    voor inline scheiders, en door pijltje voor de bijlagen-tabel
    (Develop 1/2/3 -> Protocol/Rapport).
2026-05-09 Develop 3 docs: PNG-only links, em dashes weg, Resultaten uitgebreid
    docs/develop_3.md:
    - Visuele uitwerkingen alleen nog als PNG (overkoepelende HTML weg).
    - Stakeholder map, customer journey, service blueprint links naar PNG.
    - Em dashes door komma vervangen, en-dashes in numerieke ranges blijven.
    - Microinteractions tabel: feedback-kolom expliciet als voorbeeld
    gemarkeerd, met verwijzing naar de drie MVP-koppelingen na user-test.
    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
2026-06-11 Vervang M3-insert/stud door 3D-geprinte schroefdraad + toon fasenamen als links
    - Stok-handvat koppeling is nu een mee-geprinte schroefdraad i.p.v. messing
    heatset-insert + metalen M3-stud (README, deliver, bom, wiring, build_guide, cad)
    - Ongerelateerde M3-referenties (kompas-as, cap/case-schroeven, signaal M3) blijven
    - Inhoudstafel: faseverdieping toont nu klikbare namen (Discovery, Definition, ...)
2026-06-11 Deliver: voeg assembly-render (eindproduct) en productfoto (prototype) toe
2026-06-11 Consistentie-audit fixes + build guide 3D-print/elektronica visuals
    Consistentie:
    - M4/M6/M9 overal gelijkgezet (M4=bocht nadert, M6=route-afwijking, M9=batterij low)
    - Mario/Herman achtergrond uniform (Mario verloor zicht op 18, Herman blind sinds geboorte)
    - Develop 3-motor = coin vibratiemotor (ERM), niet LRA
    - UG-nummering Develop 3 hernummerd naar UG8-UG12 (geen botsing met Develop 2)
    - Tijdlijn-maanden gelijk aan testdatums (Mrt/Apr/Mei/Jun 2026); voorpagina-datum geupdatet
    - UG4/UG5 eerlijk gerapporteerd in Develop 2; 9->10 trilpatronen
    Build guide / CAD:
    - 3D-print afbeelding + echte STL-bestanden in Sectie 1
    - Assy Elek afbeelding in Sectie 2
    - cad/exports/README en STL-bestanden t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
    [Kompas_3Dprint.stl, behuizingstok_3Dprint.stl, boxhold_3Dprint.stl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]
2026-06-13 Kleur: finaal prototype is olijfgroen; onderzoek = contrast leidend (develop_3 + infographics)
2026-06-13 Deliver: benoem Adafruit DRV2605L vibration driver expliciet in hardware
2026-06-13 Voeg werkende firmware + telefoon-app toe (handvat, controller, app)
    Brengt de software-laag van het prototype in deze branch, ZONDER de bestaande
    docs/img/README/sensepath_esp32/sensepath_pio van deze branch te wijzigen:
    - src/firmware/handle (ESP32-S3): servo-kompas, haptiek, audio, WiFi-webserver
    - src/firmware/controller (ESP32-C3): encoder + afslag-cues via ESP-NOW
    - src/firmware/shared + tools + platformio.ini + .gitignore
    - src/app: telefoon-app (index.html) + mock-server + zelfstandige demo.html
    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
2026-06-13 Deliver: verwijs naar firmware/software (collega) + STEP 3D-model van handvat
    - Reproduceerbaarheid-tabel en README-bijlagen verwijzen nu naar docs/software.md,
    src/firmware/handle + controller en src/app
    - Voeg volledig 3D-model cad/Finaal Prototype.stp toe en verwijs ernaar
    - Geen inhoudelijke wijziging aan de firmware/software van de collega
2026-06-13 BOM en wiring: consistentie + schakeling-foto handvat
    bom.md
    - productlink-kolom overal weg, "uit pakket van X" notatie behouden
    - aluminium pin (sectie 8) en rocker switch (sectie 11) verwijderd
    - project-wide schoongemaakt: JST-PH connectoren, decoupling-elco,
    pull-down weerstand, krimpkous, schroeven, epoxy en dubbelzijdige
    tape weg ; jumper wires + perfboard + soldeer blijven
    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
